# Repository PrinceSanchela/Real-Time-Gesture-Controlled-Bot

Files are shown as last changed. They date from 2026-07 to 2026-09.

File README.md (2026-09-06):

# Real-Time Gesture Controlled Robot









An end-to-end, low-latency vision-controlled robotic platform. This project integrates custom-trained **YOLOv8** hand-gesture recognition with an **ESP32** microcontroller and dual **BTS7960 43A H-Bridge** motor drivers via a high-throughput **asynchronous WebSocket** protocol.

Both dedicated **CPU** (`main.cpu.py`) and **CUDA GPU** (`main.cuda.py`) runtimes are supported, complemented by an interactive dual-motor serial calibration utility, custom model training pipeline on Google Colab, and complete KiCad electrical schematics.

---

## System Architecture

```
┌─────────────────┐       ┌───────────────────────────┐       ┌────────────────────────┐
│  HD USB Camera  │ ───>  │  OpenCV Frame Processing  │ ───>  │   YOLOv8 Deep Model    │
│  (30 / 60 FPS)  │       │ (Mirror Flip, 320x320 px) │       │ (CPU or CUDA Pipeline) │
└─────────────────┘       └───────────────────────────┘       └───────────┬────────────┘
                                                                          │ Detected Gesture
                                                                          ▼
┌─────────────────┐       ┌───────────────────────────┐       ┌────────────────────────┐
│ Dual High-Power │       │     ESP32 NodeMCU-32S     │       │ Non-Blocking Async     │
│ BTS7960 Drivers │ <───  │ Hardware LEDC PWM (5 kHz) │ <───  │ WebSocket Sender Queue │
│ (Left & Right)  │       │  Watchdog Timer (1000 ms) │ (WiFi)│ (maxsize=1, no lag)    │
└────────┬────────┘       └───────────────────────────┘       └────────────────────────┘
         │
         ▼
┌─────────────────┐
│ 2x 12V High-    │
│ Torque Motors   │
└─────────────────┘
```

### Engineering Highlights

1. **Zero-Latency Network Pipeline**: 
   The camera ingestion and YOLO inference loops are completely decoupled from network operations. Commands are dispatched through a single-slot daemon worker queue (`queue.Queue(maxsize=1)`), dropping outdated frames during network jitter to ensure the robot responds only to the freshest command.
2. **Dynamic Heartbeat & Watchdog Safety**:
   - Python client sends continuous state packets every `200 ms` to maintain link integrity.
   - The ESP32 firmware features an active hardware watchdog (`SIGNAL_TIMEOUT = 1000 ms`). If the computer crashes, disconnects, or WiFi drops for over 1 second, all PWM outputs immediately zero out, preventing runaway collisions.
3. **Dual Runtime Optimization**:
   - `main.cpu.py`: Explicit PyTorch intra-op thread allocation (`torch.set_num_threads`), tuned for laptops and single-board computers without discrete GPUs.
   - `main.cuda.py`: Direct GPU tensor inference with explicit CUDA memory cache purging on teardown.
4. **Isolated Dual Power Architecture**:
   Heavy inductive motor loads draw high surge currents. The circuit isolates the 12V high-discharge battery rail from the 5V ESP32 logic rail via an LM2596 step-down buck converter with a common ground plane, eliminating microcontroller brownouts.

---

## Hardware Schematic & Circuit Design

The schematic was designed in **KiCad 10** and validated for high-power DC motor control.

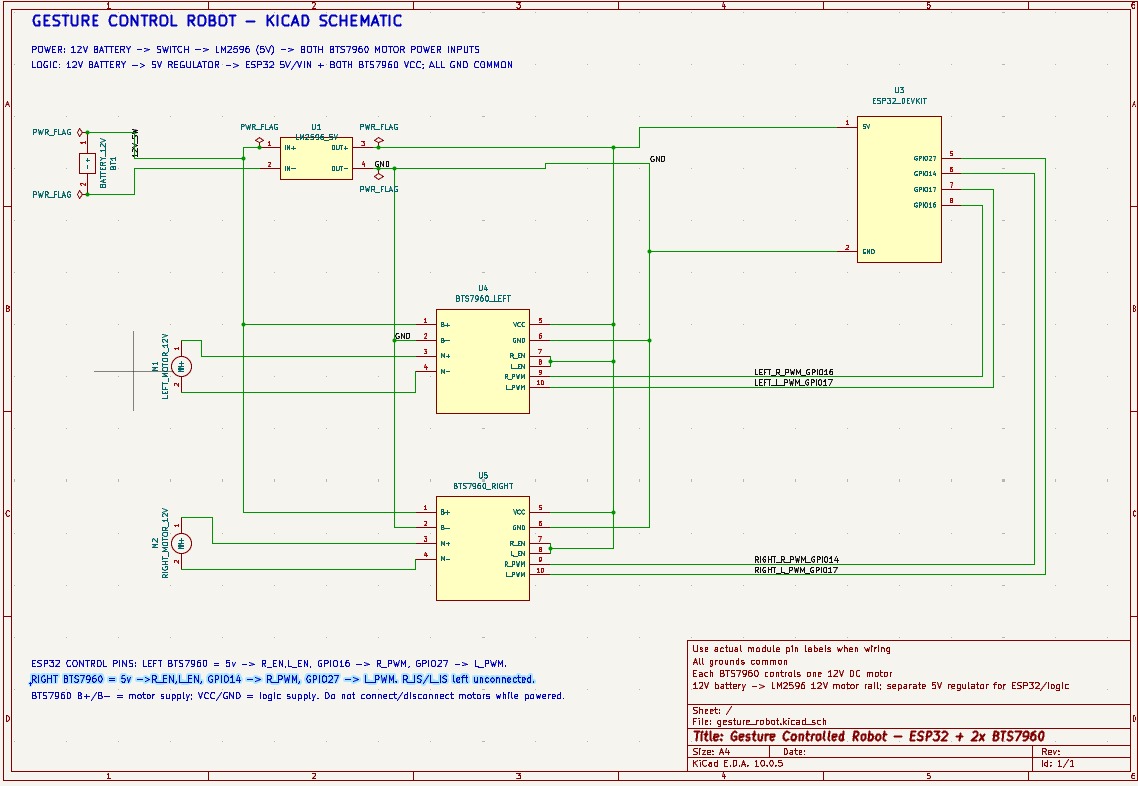
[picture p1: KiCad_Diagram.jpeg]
KiCad Circuit Schematic


*KiCad source schematic file:* [`gesture_robot.kicad_sch`](./gesture_robot.kicad_sch)

### Bill of Materials (BOM)

| Component | Specification | Function |
| :--- | :--- | :--- |
| **Microcontroller** | ESP32 NodeMCU (30-pin / 38-pin) | Real-time WebSocket server, PWM generation, watchdog |
| **Motor Drivers** | 2x BTS7960 (IBT-2) 43A H-Bridge | Independent high-current forward/reverse motor drive |
| **Drive Motors** | 2x 12V High-Torque Geared DC Motors | Differential drive locomotion |
| **Logic Power** | LM2596 DC-DC Buck Converter | Steps down 12V battery rail to clean 5V logic |
| **Main Battery** | 12V Li-ion / 3S LiPo / Lead-Acid | Power delivery for motors and buck converter |
| **Vision Input** | USB Webcam or Integrated Camera | Captures hand gestures for real-time inference |

### Pinout & Wiring Table

> [!IMPORTANT]
> Both BTS7960 drivers must share a common ground (`GND`) with the ESP32 and the LM2596 buck converter. Keep `VCC` on the logic header of BTS7960 connected to `5V` (not 3.3V) to guarantee proper gate driver saturation.

| ESP32 Pin | Connected Component | Target Pin | Description |
| :--- | :--- | :--- | :--- |
| **GPIO 16** | Left BTS7960 | `L_RPWM` | Left Motor Forward PWM |
| **GPIO 17** | Left BTS7960 | `L_LPWM` | Left Motor Reverse PWM |
| **GPIO 27** | Right BTS7960 | `R_RPWM` | Right Motor Forward PWM |
| **GPIO 14** | Right BTS7960 | `R_LPWM` | Right Motor Reverse PWM |
| **VIN / 5V** | LM2596 Buck Converter | `OUT+ (5V)` | 5V Power supply for ESP32 & Driver Logic |
| **GND** | LM2596 & BTS7960 | `GND / OUT-` | Common System Ground |
| **5V Rail** | Left & Right BTS7960 | `R_EN` & `L_EN` | Bridge Enable Pins (Tied High to 5V) |

---

## Gesture Control Mapping

The custom YOLOv8 model (`best.pt`) was trained to classify five distinct hand postures:

| Gesture | Class Name | Robot Action | Motor Actuation Pattern |
| :---: | :---: | :---: | :--- |
| 👌 | `okay` | **FORWARD** | Left & Right motors drive forward at calibrated baseline PWM |
| 🤟 | `spiderman` | **BACKWARD** | Left & Right motors drive reverse at calibrated baseline PWM |
| 👎 | `dislike` | **LEFT** | Left motor reverse/hold, Right motor forward (pivot turn) |
| 👍 | `like` | **RIGHT** | Left motor forward, Right motor reverse/hold (pivot turn) |
| ✊ | `rock` | **STOP** | All PWM signals zeroed (`0, 0, 0, 0`) |
| *None* | *(No box detected)* | **STOP** | Failsafe timeout stops the vehicle immediately |

---

## Model Training & Evaluation (Google Colab)

The gesture recognition model was trained in the cloud using **Google Colab** with NVIDIA GPU acceleration.

  
*Full training notebook source:* [`training/train_gesture_yolo.ipynb`](./training/train_gesture_yolo.ipynb) | *Dataset schema:* [`training/data.yaml`](./training/data.yaml)

### Training Configuration

- **Base Architecture**: YOLOv8n (Nano backbone, 3.01M parameters, 8.2 GFLOPs)
- **Hardware Acceleration**: Google Colab NVIDIA Tesla T4 (15 GB VRAM)
- **Training Duration**: 50 Epochs (~1.25 hours) with AdamW optimizer (`lr=0.0011`, `momentum=0.9`)
- **Dataset Composition**: 992 labeled images (993 gesture instances) across two merged datasets with automated label remapping.
- **Data Augmentations**:
  - Rotation: $\pm 15.0^\circ$
  - Horizontal Flip: 50%
  - Vertical Flip: 20%
  - HSV Color Jitter: Hue=0.015, Saturation=0.7, Value=0.4
  - Random Erasing / Cutout: 10%
  - Perspective Transformation: 0.001
  - Mosaic: Active for first 40 epochs (closed for final 10 epochs for fine-grained boundary refinement)

### Validation Performance (`best.pt`)

Evaluated at 640x640 validation resolution across all 5 classes:

| Class | Instances | Precision (P) | Recall (R) | mAP@50 | mAP@50-95 |
| :--- | :---: | :---: | :---: | :---: | :---: |
| **Overall (All Classes)** | **993** | **0.998 (99.8%)** | **0.994 (99.4%)** | **0.993 (99.3%)** | **0.752 (75.2%)** |
| `okay` | 88 | 0.998 | 0.989 | 0.985 | 0.726 |
| `spiderman` | 72 | 1.000 | 0.999 | 0.995 | 0.731 |
| `like` | 278 | 0.995 | 0.993 | 0.995 | 0.773 |
| `dislike` | 275 | 0.996 | 0.994 | 0.995 | 0.770 |
| `rock` | 280 | 1.000 | 0.997 | 0.995 | 0.762 |

*Inference Speed on Tesla T4:* Pre-process `0.2 ms`, Inference `2.7 ms`, Post-process `2.6 ms` per frame.

---

## Firmware Setup (Arduino IDE)

The [`Arduino IDE Codes/`](./Arduino%20IDE%20Codes/) directory contains two sketches:

### 1. Motor Calibration Utility (`calibration.ino`)
DC motors rarely spin at identical speeds due to gearbox tolerances and friction. This sketch provides an interactive **Serial CLI** (115200 baud) over USB to dynamically trim differential motor speeds while the robot is running:

```
Input format: [Target][+/-Value or DirectNumber] + Enter
  L   -> Straight   : Left motor  (e.g., L+5, L-2, L210)
  R   -> Straight   : Right motor (e.g., R+3, R-5, R190)
  TLL -> Turn-Left  : Left motor  (e.g., TLL0, TLL+5)
  TLR -> Turn-Left  : Right motor (e.g., TLR160, TLR+5)
  TRL -> Turn-Right : Left motor  (e.g., TRL165, TRL-3)
  TRR -> Turn-Right : Right motor (e.g., TRR0, TRR+2)
```

Use this tool to find your chassis's straight-line equilibrium before uploading the final production sketch.

### 2. Production Firmware (`main.ino`)
- Flashed once trimming is finalized.
- Connects to your local 2.4 GHz WiFi network.
- Hosts the WebSocket server on port `81`.
- Receives motion commands (`FORWARD`, `BACKWARD`, `LEFT`, `RIGHT`, `STOP`) and handles hardware PWM signals.
- Runs the 1000 ms watchdog failsafe.

#### Flashing Instructions
1. Open [`Arduino IDE Codes/main.ino`](./Arduino%20IDE%20Codes/main.ino) in Arduino IDE.
2. Install the required library via the Library Manager:
   - **WebSockets** by *Markus Sattler*
3. Select your ESP32 board (`Tools -> Board -> ESP32 Arduino -> ESP32 Dev Module`).
4. Update your WiFi credentials:
   ```cpp
   const char* ssid = "YOUR_WIFI_SSID";
   const char* password = "YOUR_WIFI_PASSWORD";
   ```
5. Upload the sketch and open the Serial Monitor at **115200 baud**.
6. Note the assigned IP address printed upon connection (e.g., `10.97.227.48`).

---

## Python Software Setup

### Prerequisites
- Python 3.9, 3.10, or 3.11
- Working webcam
- Network connectivity on the same subnet as the ESP32

### 1. Clone & Environment Setup

```bash
git clone https://github.com/<your-username>/Real-Time-Gesture-Controlled-Robot.git
cd Real-Time-Gesture-Controlled-Robot

# Create a virtual environment
python -m venv venv

# Activate the virtual environment
# Windows (PowerShell):
.\venv\Scripts\Activate.ps1
# Windows (cmd):
.\venv\Scripts\activate.bat
# Linux / macOS:
source venv/bin/activate
```

### 2. Dependency Installation

Choose the configuration that matches your host hardware:

#### Option A: CPU Runtime (Any PC / Laptop)
```bash
pip install -r requirements-cpu.txt
```

#### Option B: CUDA GPU Runtime (NVIDIA GPU with CUDA 12.1+)
```bash
pip install -r requirements-cuda.txt
```

*(Alternatively, run `pip install -r requirements.txt` for standard PyPI dependencies).*

### 3. Configure ESP32 IP Address

Open [`main.cpu.py`](./main.cpu.py) or [`main.cuda.py`](./main.cuda.py) and update `ESP32_IP` with the IP displayed in the Arduino Serial Monitor:

```python
# ESP32 WebSocket Settings
ESP32_IP = "10.97.227.48"  # Replace with your ESP32's current IP
WEBSOCKET_PORT = 81
```

### 4. Running the Controller

**For CPU Inference:**
```bash
python main.cpu.py
```

**For CUDA GPU Inference:**
```bash
python main.cuda.py
```

- Press `q` while focused on the video feed to safely shut down the camera, zero the robot motors, and exit.

---

## Repository Structure

```
.
├── CONTRIBUTING.md           # Contribution guidelines & team engineering roles
├── Arduino IDE Codes/
│   ├── calibration.ino       # Interactive serial CLI for live differential motor trimming
│   └── main.ino              # Production ESP32 firmware (WebSocket server + watchdog)
├── KiCad_Diagram.jpeg        # Full schematic diagram render
├── LICENSE                   # MIT License
├── README.md                 # Complete project documentation
├── best.pt                   # Trained YOLOv8 gesture recognition weights
├── gesture_robot.kicad_sch   # KiCad 10 schematic source file
├── main.cpu.py               # CPU-optimized real-time vision & WebSocket controller
├── main.cuda.py              # CUDA GPU-accelerated vision & WebSocket controller
├── requirements-cpu.txt      # Dependency manifest for CPU installations
├── requirements-cuda.txt     # Dependency manifest for CUDA GPU installations
├── requirements.txt          # Universal dependency manifest
└── training/
    ├── data.yaml             # 5-class YOLOv8 dataset configuration
    └── train_gesture_yolo.ipynb # Complete Google Colab training notebook
```

---

## Performance & Latency Profile

| Metric | CPU Pipeline (`main.cpu.py`) | CUDA GPU Pipeline (`main.cuda.py`) |
| :--- | :--- | :--- |
| **Inference Hardware** | Intel Core i7 / AMD Ryzen (Multi-thread) | NVIDIA RTX 3060 / 4060 or better |
| **Inference Latency** | ~25 - 35 ms | ~5 - 8 ms |
| **Frame Processing Rate** | 25 - 35 FPS | 60+ FPS (Camera bottlenecked) |
| **Network Dispatch Latency**| < 3 ms (Local LAN) | < 3 ms (Local LAN) |
| **End-to-End Latency** | **< 40 ms** | **< 12 ms** |

---

## Troubleshooting & Engineering Notes

### 1. ESP32 Resets When Motors Start (Brownout)
- **Cause**: Motors draw high inrush currents at stall/startup, pulling the supply rail down below the ESP32's internal 2.7V brownout detector threshold.
- **Fix**: Verify that the LM2596 buck converter powers the ESP32 through a separate tap, with a 470 µF–1000 µF electrolytic capacitor placed across the buck converter output. Never power the BTS7960 motor rails directly from the ESP32 5V/VIN pin.

### 2. WebSocket Connection Refused
- Ensure your computer and ESP32 are connected to the **same Wi-Fi router** (and that client isolation / AP isolation is turned off in router settings).
- Verify the IP address printed on the ESP32 Serial Monitor matches the `ESP32_IP` string in the Python script.
- Ensure port `81` is not blocked by local OS firewall policies.

### 3. One Motor Runs in Reverse
- Invert the respective RPWM and LPWM pin assignments in `main.ino` or swap the `M+` and `M-` leads on the BTS7960 terminal block.

### 4. Camera Ingestion Lag
- Keep `IMG_SIZE = 320` in the Python script. Hand posture bounding boxes do not require 640x640 resolutions, and 320x320 cuts tensor compute time by over 60%.

---

## Team & Contributors

Developed as a collaborative engineering robotics project by our core team:

| Contributor | GitHub Profile | Engineering Role |
| :--- | :--- | :--- |
| **Prince Sanchela** | [@PrinceSanchela](https://github.com/PrinceSanchela) | **Core Robotics & CPU Pipeline**: Hardware schematics, ESP32 firmware, CPU vision client (`main.cpu.py`), and system integration |
| **Vedant Chauhan** | [@VedantChauhan14](https://github.com/VedantChauhan14) | **ML & CUDA GPU Pipeline**: Google Colab training, YOLOv8 evaluation, dataset merging, and CUDA vision client (`main.cuda.py`) |
| **Aastha** | [@Aastha150](https://github.com/Aastha150) | **Computer Vision & Annotation**: Gesture image collection, multi-class bounding box labeling |
| **Aahyam Rehman** | [@rehmanaahyam](https://github.com/rehmanaahyam) | **Mechanical Fabrication**: Robot chassis assembly, motor mounting, and locomotion testing |
| **Aakarsh** | [@akarsh-616](https://github.com/akarsh-616) | **Power Systems**: Wiring harness, LM2596 buck regulation, and electrical hardware testing |
| **Het Zaveri** | [@Het-Zaveri](https://github.com/Het-Zaveri) | **Telemetry & QA**: WebSocket latency benchmarking, watchdog safety verification, and QA |

For contribution guidelines, code standards, and PR workflows, please see [**CONTRIBUTING.md**](./CONTRIBUTING.md).

---

## License

This project is licensed under the [MIT License](./LICENSE) - see the LICENSE file for details.

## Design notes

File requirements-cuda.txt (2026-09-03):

# ==============================================================================
# Real-Time Gesture Controlled Robot - GPU / CUDA Runtime Requirements
# ==============================================================================
# Optimized for NVIDIA GPU acceleration (CUDA 12.1+ / 11.8).
# Ensure compatible NVIDIA drivers (>= 525.60.13) are installed.
#
# Installation:
#   pip install -r requirements-cuda.txt
# ==============================================================================

# PyTorch CUDA 12.1 binary distribution from official PyTorch repository
--extra-index-url https://download.pytorch.org/whl/cu121

# Core Deep Learning & Computer Vision
torch>=2.0.0
torchvision>=0.15.0
ultralytics>=8.0.100
opencv-python>=4.8.0.76

# Network Communication
websocket-client>=1.6.1

# Numerical Utilities
numpy>=1.23.5,<2.0.0
Pillow>=9.5.0

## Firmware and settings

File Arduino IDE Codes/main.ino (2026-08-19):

#include <WiFi.h>
#include <WebSocketsServer.h>

// Wifi Settings

const char* ssid = "Your-SSID";
const char* password = "Your-Password";

//BTS Motor Driver Pins

#define LEFT_RPWM_PIN 16  
#define LEFT_LPWM_PIN 17  
#define RIGHT_RPWM_PIN 27 
#define RIGHT_LPWM_PIN 14 

#define PWM_FREQ       5000  
#define PWM_RESOLUTION 8     

const int L_SPEED  = 230;  
const int R_SPEED = 190;  
const int TRL_SPEED = 165;
const int TLR_SPEED = 200;


// WebSocket & WatchDog

WebSocketsServer webSocket = WebSocketsServer(81);

unsigned long lastSignalTime = 0;
// INCREASED TIMEOUT: Now waits 1 full second before auto-stopping
const unsigned long SIGNAL_TIMEOUT = 1000; 
bool isMoving = false; 
String currentAction = "STOP"; // Track current action for debugging

// Forward Declarations
void stopRobot();
void moveForward();
void moveBackward();
void turnLeft();
void turnRight();


// WebSocket Event Handler 

void webSocketEvent(uint8_t clientNum, WStype_t type, uint8_t* payload, size_t length) {

  switch (type) {
    case WStype_CONNECTED: {
      Serial.println("\n[WEBSOCKET] Python Connected!");
      webSocket.sendTXT(clientNum, "ESP32 Connected");
      break;
    }
    case WStype_DISCONNECTED:
      Serial.println("\n[WEBSOCKET] Python Disconnected! Stopping.");
      stopRobot();
      break;
    case WStype_TEXT: {
      String gesture = String((char*)payload).substring(0, length);
      gesture.trim();

      // Reset the safety timer every time ANY command arrives
      lastSignalTime = millis(); 

      if (gesture.indexOf("FORWARD") != -1) moveForward();
      else if (gesture.indexOf("BACKWARD") != -1) moveBackward();
      else if (gesture.indexOf("LEFT") != -1) turnLeft();
      else if (gesture.indexOf("RIGHT") != -1) turnRight();
      else if (gesture.indexOf("STOP") != -1) stopRobot();
      
      break;
    }
    default:
      break;
  }
}

// Motor Control Functions (WITH DEBUG PRINTS)

void driveLeftMotor(int forwardSpeed, int reverseSpeed) {
  ledcWrite(LEFT_RPWM_PIN, forwardSpeed);
  ledcWrite(LEFT_LPWM_PIN, reverseSpeed);
  
  // Debug print to verify PWM values are actually triggering
  Serial.print("  -> LEFT Motor PWM  | FWD: "); 
  Serial.print(forwardSpeed); 
  Serial.print(" | REV: "); 
  Serial.println(reverseSpeed);
}

void driveRightMotor(int forwardSpeed, int reverseSpeed) {
  ledcWrite(RIGHT_RPWM_PIN, forwardSpeed);
  ledcWrite(RIGHT_LPWM_PIN, reverseSpeed);
  
  // Debug print to verify PWM values are actually triggering
  Serial.print("  -> RIGHT Motor PWM | FWD: "); 
  Serial.print(forwardSpeed); 
  Serial.print(" | REV: "); 
  Serial.println(reverseSpeed);
}

void stopRobot() {
  if (currentAction == "STOP") return; // Prevent spamming
  currentAction = "STOP";
  isMoving = false;
  
  Serial.println("\n=== EXECUTING: STOP ===");
  driveLeftMotor(0, 0);
  driveRightMotor(0, 0);
}

void moveForward() {
  if (currentAction != "FORWARD") {
    currentAction = "FORWARD";
    Serial.println("\n=== EXECUTING: FORWARD ===");
  }
  isMoving = true;
  driveLeftMotor(L_SPEED, 0);
  driveRightMotor(R_SPEED, 0);
}

void moveBackward() {
  if (currentAction != "BACKWARD") {
    currentAction = "BACKWARD";
    Serial.println("\n=== EXECUTING: BACKWARD ===");
  }
  isMoving = true;
  driveLeftMotor(0, L_SPEED);
  driveRightMotor(0, R_SPEED);
}

void turnLeft() {
  if (currentAction != "LEFT") {
    currentAction = "LEFT";
    Serial.println("\n=== EXECUTING: LEFT ===");
  }
  isMoving = true;
  driveLeftMotor(0, 0);
  driveRightMotor(TLR_SPEED, 0);
}

void turnRight() {
  if (currentAction != "RIGHT") {
    currentAction = "RIGHT";
    Serial.println("\n=== EXECUTING: RIGHT ===");
  }
  isMoving = true;
  driveLeftMotor(TRL_SPEED, 0);
  driveRightMotor(0, 0);
}


void setup() {
  Serial.begin(115200);
  delay(1000);

  Serial.println("\n================================");
  Serial.println("ESP32 BTS DRIVER GESTURE ROBOT");
  Serial.println("================================");

  // Initialize PWM Pins (ESP32 Core 3.x API)
  if(ledcAttach(LEFT_RPWM_PIN, PWM_FREQ, PWM_RESOLUTION)) Serial.println("LEFT_RPWM Attached.");
  if(ledcAttach(LEFT_LPWM_PIN, PWM_FREQ, PWM_RESOLUTION)) Serial.println("LEFT_LPWM Attached.");
  if(ledcAttach(RIGHT_RPWM_PIN, PWM_FREQ, PWM_RESOLUTION)) Serial.println("RIGHT_RPWM Attached.");
  if(ledcAttach(RIGHT_LPWM_PIN, PWM_FREQ, PWM_RESOLUTION)) Serial.println("RIGHT_LPWM Attached.");

  // Connect WiFi
  Serial.print("Connecting to WiFi");
  WiFi.begin(ssid, password);
  while (WiFi.status() != WL_CONNECTED) {
    delay(500);
    Serial.print(".");
  }
  Serial.print("\nWiFi Connected! IP: ");
  Serial.println(WiFi.localIP());

  webSocket.begin();
  webSocket.onEvent(webSocketEvent);
}

void loop() {
  webSocket.loop();

  // WATCHDOG TIMER
  
  if (isMoving && (millis() - lastSignalTime > SIGNAL_TIMEOUT)) {
    Serial.println("\n[WATCHDOG] Gesture signal timed out (1 second passed). Auto-stopping.");
    stopRobot();
  }
}

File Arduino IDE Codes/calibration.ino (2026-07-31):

#include <WiFi.h>
#include <WebSocketsServer.h>

// Wifi Settings

const char* ssid = "Your-SSID";
const char* password = "Your-PassWord";

// BTS Motor Driver Pins

#define LEFT_RPWM_PIN  16  
#define LEFT_LPWM_PIN  17  
#define RIGHT_RPWM_PIN 14 
#define RIGHT_LPWM_PIN 27

#define PWM_FREQ       5000  
#define PWM_RESOLUTION 8     // 0-255

// Calibrated Baseline Speed

int leftMotorSpeed  = 190;
int rightMotorSpeed = 190;

// Left turn individual motor speeds
int turnLeft_LeftMotor   = 0;    // Left wheel during LEFT turn (0 = pivot)
int turnLeft_RightMotor  = 150;  // Right wheel during LEFT turn

// Right turn individual motor speeds
int turnRight_LeftMotor  = 150;  // Left wheel during RIGHT turn
int turnRight_RightMotor = 0;    // Right wheel during RIGHT turn (0 = pivot)

// Tracks active real-time output PWM values to print accordingly
int activeLeftFwdPWM  = 0;
int activeLeftRevPWM  = 0;
int activeRightFwdPWM = 0;
int activeRightRevPWM = 0;

// Websocket & Timers

WebSocketsServer webSocket = WebSocketsServer(81);

unsigned long lastSignalTime = 0;
const unsigned long SIGNAL_TIMEOUT = 1000; 

unsigned long lastPrintTime = 0;
const unsigned long PRINT_INTERVAL = 1000; // Serial monitor update rate

bool isMoving = false; 
String currentAction = "STOP";

// Forward Declarations
void stopRobot();
void moveForward();
void moveBackward();
void turnLeft();
void turnRight();
void refreshCurrentMovement();
void handleSerialCalibration();
void printContinuousStatus();


// WebSocket Event Handler 

void webSocketEvent(uint8_t clientNum, WStype_t type, uint8_t* payload, size_t length) {
  switch (type) {
    case WStype_CONNECTED:
      Serial.println("\n[WEBSOCKET] Controller Connected!");
      webSocket.sendTXT(clientNum, "ESP32 Connected");
      break;

    case WStype_DISCONNECTED:
      Serial.println("\n[WEBSOCKET] Controller Disconnected! Stopping.");
      stopRobot();
      break;

    case WStype_TEXT: {
      String gesture = String((char*)payload).substring(0, length);
      gesture.trim();

      lastSignalTime = millis(); 

      if (gesture.indexOf("FORWARD") != -1) moveForward();
      else if (gesture.indexOf("BACKWARD") != -1) moveBackward();
      else if (gesture.indexOf("LEFT") != -1) turnLeft();
      else if (gesture.indexOf("RIGHT") != -1) turnRight();
      else if (gesture.indexOf("STOP") != -1) stopRobot();
      break;
    }
    default:
      break;
  }
}


// Motor Contoller Functions

void driveMotors(int leftFwd, int leftRev, int rightFwd, int rightRev) {
  activeLeftFwdPWM  = leftFwd;
  activeLeftRevPWM  = leftRev;
  activeRightFwdPWM = rightFwd;
  activeRightRevPWM = rightRev;

  ledcWrite(LEFT_RPWM_PIN, leftFwd);
  ledcWrite(LEFT_LPWM_PIN, leftRev);
  ledcWrite(RIGHT_RPWM_PIN, rightFwd);
  ledcWrite(RIGHT_LPWM_PIN, rightRev);
}

void stopRobot() {
  if (currentAction == "STOP") return;
  currentAction = "STOP";
  isMoving = false;
  driveMotors(0, 0, 0, 0);
}

void moveForward() {
  currentAction = "FORWARD";
  isMoving = true;
  driveMotors(leftMotorSpeed, 0, rightMotorSpeed, 0);
}

void moveBackward() {
  currentAction = "BACKWARD";
  isMoving = true;
  driveMotors(0, leftMotorSpeed, 0, rightMotorSpeed);
}

void turnLeft() {
  currentAction = "LEFT";
  isMoving = true;
  // Left motor reverses/holds, Right motor drives forward
  driveMotors(0, turnLeft_LeftMotor, turnLeft_RightMotor, 0);
}

void turnRight() {
  currentAction = "RIGHT";
  isMoving = true;
  // Left motor drives forward, Right motor reverses/holds
  driveMotors(turnRight_LeftMotor, 0, 0, turnRight_RightMotor);
}

void refreshCurrentMovement() {
  if (currentAction == "FORWARD") {
    moveForward();
  } else if (currentAction == "BACKWARD") {
    moveBackward();
  } else if (currentAction == "LEFT") {
    turnLeft();
  } else if (currentAction == "RIGHT") {
    turnRight();
  }
}


// Serial Status Monitor

void printContinuousStatus() {
  if (millis() - lastPrintTime >= PRINT_INTERVAL) {
    lastPrintTime = millis();

    Serial.println("----------------------------------------------------------------------------------");
    Serial.print("[ACTION: ");
    Serial.print(currentAction);
    Serial.println("]");

    // 1. Prints actual real-time PWM values feeding the motors right now
    Serial.print("  ACTIVE OUTPUT -> ");
    Serial.print("LEFT MOTOR [FWD: ");
    Serial.print(activeLeftFwdPWM);
    Serial.print(" | REV: ");
    Serial.print(activeLeftRevPWM);
    Serial.print("]  ||  RIGHT MOTOR [FWD: ");
    Serial.print(activeRightFwdPWM);
    Serial.print(" | REV: ");
    Serial.print(activeRightRevPWM);
    Serial.println("]");

    // 2. Prints current calibrated reference table
    Serial.print("  CALIBRATION   -> ");
    Serial.print("Fwd/Bwd Base (L: ");
    Serial.print(leftMotorSpeed);
    Serial.print(", R: ");
    Serial.print(rightMotorSpeed);
    Serial.print(") | Turn-Left Speeds (L: ");
    Serial.print(turnLeft_LeftMotor);
    Serial.print(", R: ");
    Serial.print(turnLeft_RightMotor);
    Serial.print(") | Turn-Right Speeds (L: ");
    Serial.print(turnRight_LeftMotor);
    Serial.print(", R: ");
    Serial.print(turnRight_RightMotor);
    Serial.println(")");
    Serial.println("----------------------------------------------------------------------------------");
  }
}


// Calibration Parse

void applySpeedChange(int &targetSpeed, String valStr, const char* label) {
  int deltaOrAbsolute = valStr.toInt();

  if (valStr.startsWith("+") || valStr.startsWith("-")) {
    targetSpeed += deltaOrAbsolute;
  } else {
    targetSpeed = deltaOrAbsolute;
  }

  targetSpeed = constrain(targetSpeed, 0, 255);

  Serial.println("\n>>> [UPDATED] <<<");
  Serial.print(label);
  Serial.print(" set to: ");
  Serial.println(targetSpeed);

  refreshCurrentMovement();
}
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

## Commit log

2026-07-14 chore: initialize repository and configure gitignore for python, kicad, and arduino
2026-07-18 feat(hardware): design schematic for esp32 and dual bts7960 motor drivers
    [gesture_robot.kicad_sch]
2026-07-24 docs(hardware): add circuit schematic render and power rail isolation layout
2026-07-31 feat(firmware): add serial cli calibration tool for dual bts7960 differential drive
2026-08-19 feat(firmware): add production esp32 websocket server and 1000ms safety watchdog
2026-09-06 docs: comprehensive system documentation, wiring guides, colab link, and benchmarks
